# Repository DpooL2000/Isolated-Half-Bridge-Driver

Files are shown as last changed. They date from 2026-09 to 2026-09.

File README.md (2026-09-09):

# Isolated Half-Bridge Motor Driver

A robust, single half-bridge motor driver featuring galvanic PWM isolation and high-resolution bidirectional current sensing. Designed to safely interface a microcontroller with high-voltage motor rails while providing precise analog current feedback.



## Project Status
- **Hardware:** Complete (KiCad schematic and PCB layout finalized).
- **Firmware:** C++ driver code currently in development.

## Key Hardware Specifications
* **Gate Driver:** IR2101 with bootstrap topology (1N5819 diode / 1uF cap).
* **Power Stage:** 2x IRFZ44N N-Channel MOSFETs with 1000uF bulk smoothing.
* **Galvanic Isolation:** 2x 6N137 high-speed optocouplers protecting the logic side.
* **Current Sensing:** AD8418 bidirectional amplifier across an R002 milliohm shunt, heavily filtered (10Ω/10nF/1nF).
* **Reference Voltage:** Buffered 1.65V rail generated via MCP6002 for center-biased bidirectional sensing.

## Interface & Pinout

### Logic Side (Low Voltage)
* **PWM_H / PWM_L:** 2-Channel high-speed logic inputs (isolated via 6N137).
* **I_SENSE_OUT:** Amplified analog voltage representing motor current (centered at 1.65V).
* **VCC_LOGIC:** Input for the onboard LDO stepping down to power the opto-secondaries and IR2101.
* **GND:** Logic ground.

### Power Side (High Voltage)
* **MOTOR_V+:** Main high-voltage power rail.
* **MOTOR_OUT:** Half-bridge switching output to the motor.
* **GND_PWR:** Power ground (isolated from logic ground).

## Repository Structure
* `/Hardware` - KiCad project files (`.kicad_pro`, `.kicad_sch`, `.kicad_pcb`).
* `/Docs` - PDF schematics, board renders, and full CSV Bill of Materials.
* `/Firmware` - Placeholder for the upcoming C++ hardware abstraction and control classes. 

## Usage Notes
The design utilizes a bootstrap capacitor (C3) for the high-side MOSFET. The low-side MOSFET must be periodically pulsed on to recharge the bootstrap capacitor; do not attempt 100% duty cycle on the high side.

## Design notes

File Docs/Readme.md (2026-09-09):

# Subcircuit Documentation

## 1. Optocoupler Isolation Stage
This section safely isolates the low-voltage control logic from the high-voltage motor drive circuitry, preventing transient spikes from damaging the microcontroller.



* The circuit utilizes two 6N137 high-speed optocouplers (U11 and U4) to provide galvanic isolation for the incoming PWM signals.
* Control signals enter through a 2-pin screw terminal (J3) and pass through 330Ω current-limiting resistors (R1, R2) to drive the internal LEDs of the optocouplers.
* The secondary side of the optocouplers is powered by a 5V rail, decoupled by 0.1uF capacitors (C14, C13).
* The open-drain outputs are pulled up to the 3.3V logic rail via 1kΩ resistors (R3, R4), resulting in the isolated `CH` and `CNH` control signals.

## 2. Power Supply & Voltage Reference
This stage regulates the main battery voltage into clean logic levels and generates a stable center-bias voltage for bidirectional current sensing.



* The main battery voltage (`+BATT`) from screw terminal J1 is stepped down to 5V by an AMS1117-5.0 linear regulator (U6).
* A second regulator, an AMS1117-3.3 (U5), steps the voltage down further to provide a 3.3V rail for logic-level pull-ups and amplifier supply.
* Standard 10uF and 0.1uF capacitors are utilized on the regulator inputs and outputs for stability and transient suppression.
* A precise 1.65V reference voltage is generated using a 50% voltage divider consisting of two 10kΩ resistors (R5, R6) connected across the 3.3V rail. 
* This divider is buffered by an LMH6611 operational amplifier (U2) configured as a unity-gain follower, providing a low-impedance 1.65V source.

## 3. Half-Bridge & Bootstrap Driver
This high-power switching stage translates the isolated logic signals into the high current required to drive the motor.



* An IR2101 high/low-side driver IC (U8) manages the switching of two IRFZ44N N-channel power MOSFETs (Q1, Q2) configured in a half-bridge topology.
* Because an N-channel MOSFET on the high side requires a gate voltage higher than the main battery rail (`+BATT`), a bootstrap circuit is implemented using a 1N5819 Schottky diode (D3) and a 1uF capacitor (C3).
* The isolated control signals `CH` and `CNH` are pulled up to 5V via 1kΩ resistors (R8, R7) before feeding into the driver IC.
* The driver outputs connect to the MOSFET gates through 22Ω resistors (R13, R14) to dampen ringing and limit peak switching current.
* A 1000uF bulk electrolytic capacitor (C10) sits across the high-voltage rail and ground to smooth out heavy current demands from the motor.

## 4. Current Sensing & Analog Filtering
This circuit measures the physical output current of the half-bridge and translates it into a clean, center-biased analog voltage.



* Motor current flows through an R002 (2mΩ) inline shunt resistor (R19), creating a small voltage drop proportional to the current.
* An AD8418 high-resolution current sense amplifier (U1) measures this differential voltage.
* To reject high-frequency switching noise, the inputs to the amplifier are heavily filtered using 10Ω resistors (R25, R26), a 10nF differential capacitor (C19), and 1nF common-mode capacitors (C27, C26).
* The amplifier's reference pins (REF1 and REF2) are tied to the buffered 1.65V rail. This center-biases the output, allowing the microcontroller to read both forward and reverse motor currents.
* The final analog output passes through an RC low-pass filter (330Ω R9 and 100nF C11) before exiting via the `current analog reading` connector (J4).

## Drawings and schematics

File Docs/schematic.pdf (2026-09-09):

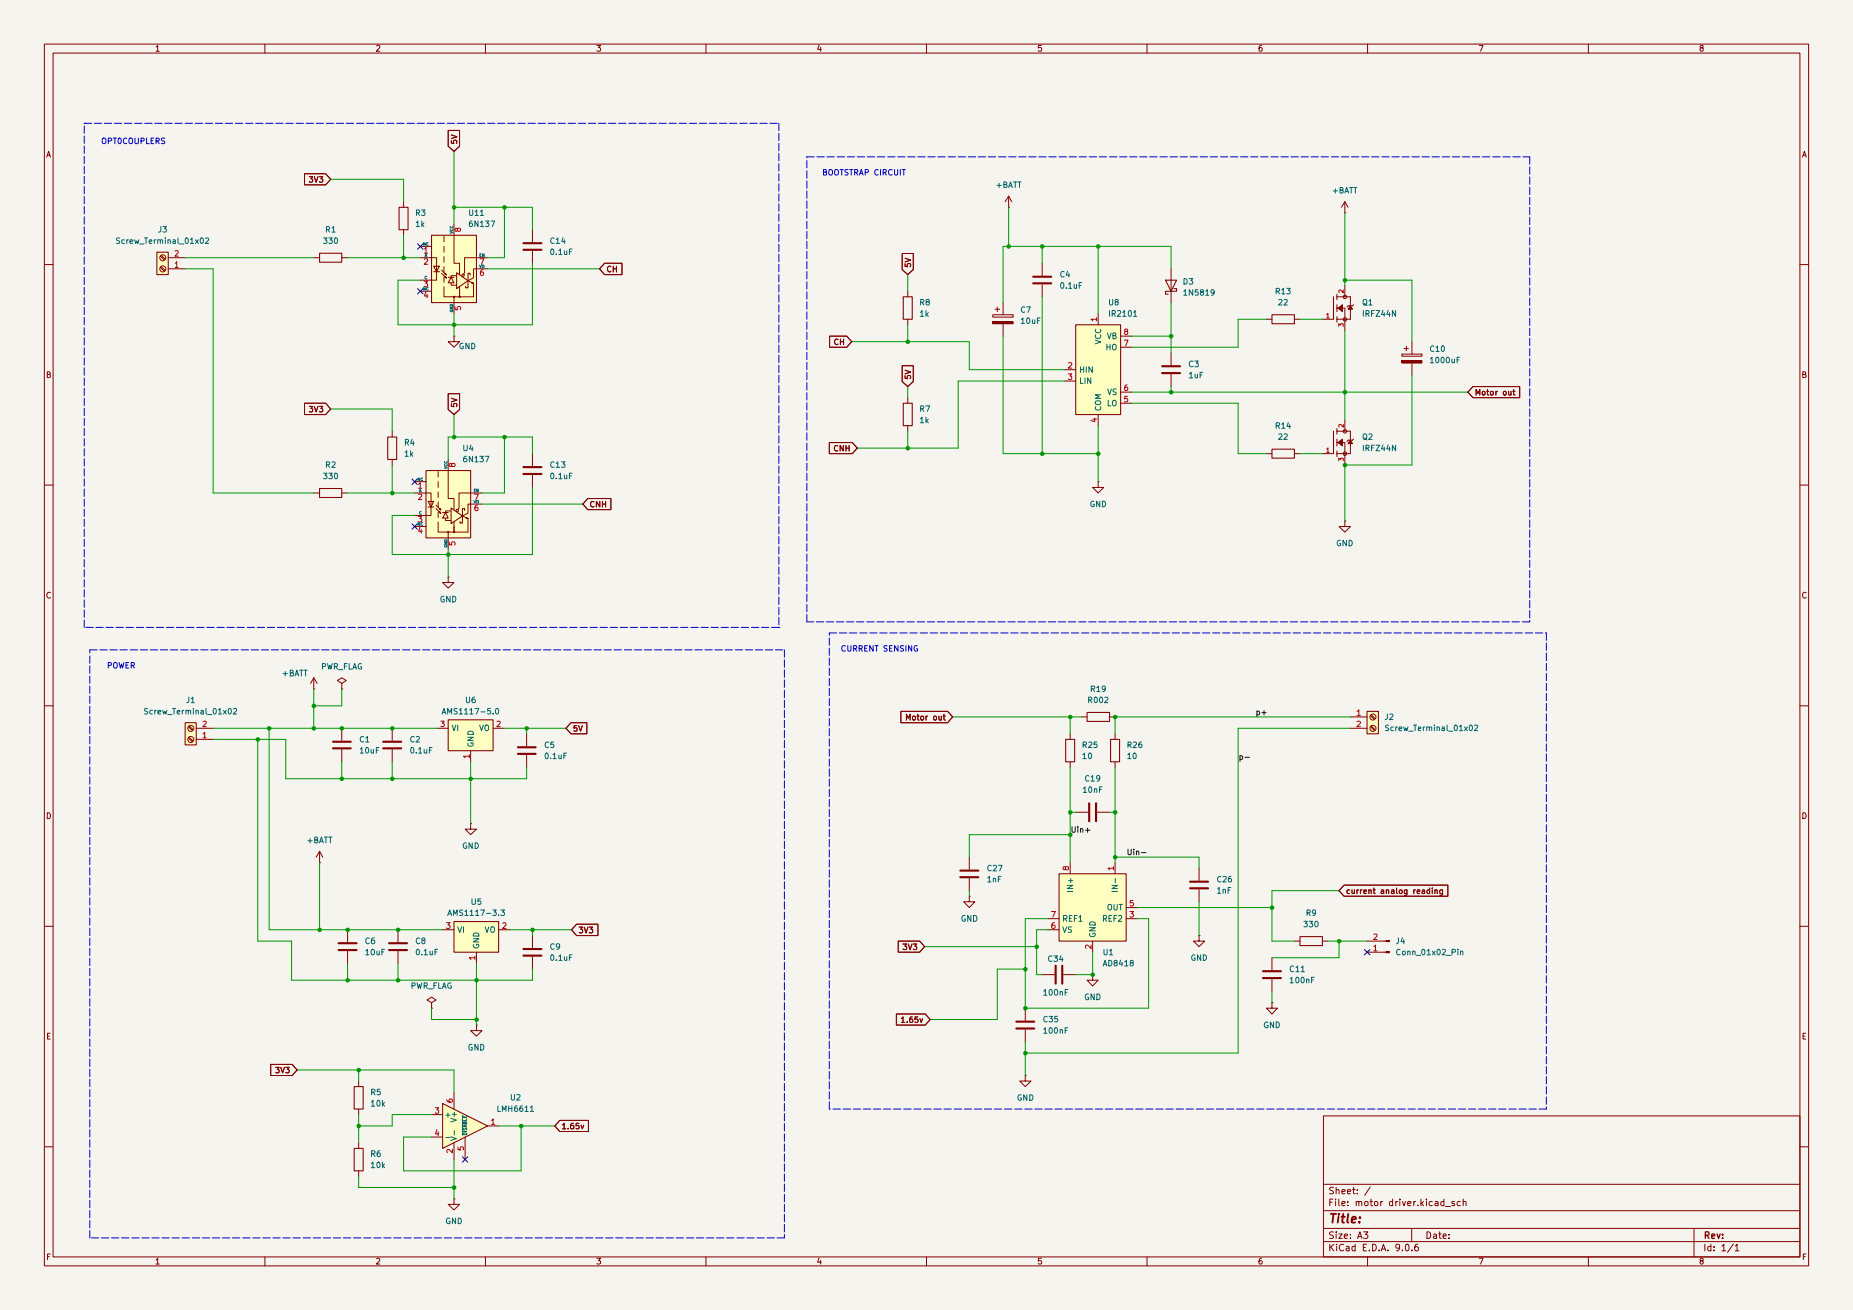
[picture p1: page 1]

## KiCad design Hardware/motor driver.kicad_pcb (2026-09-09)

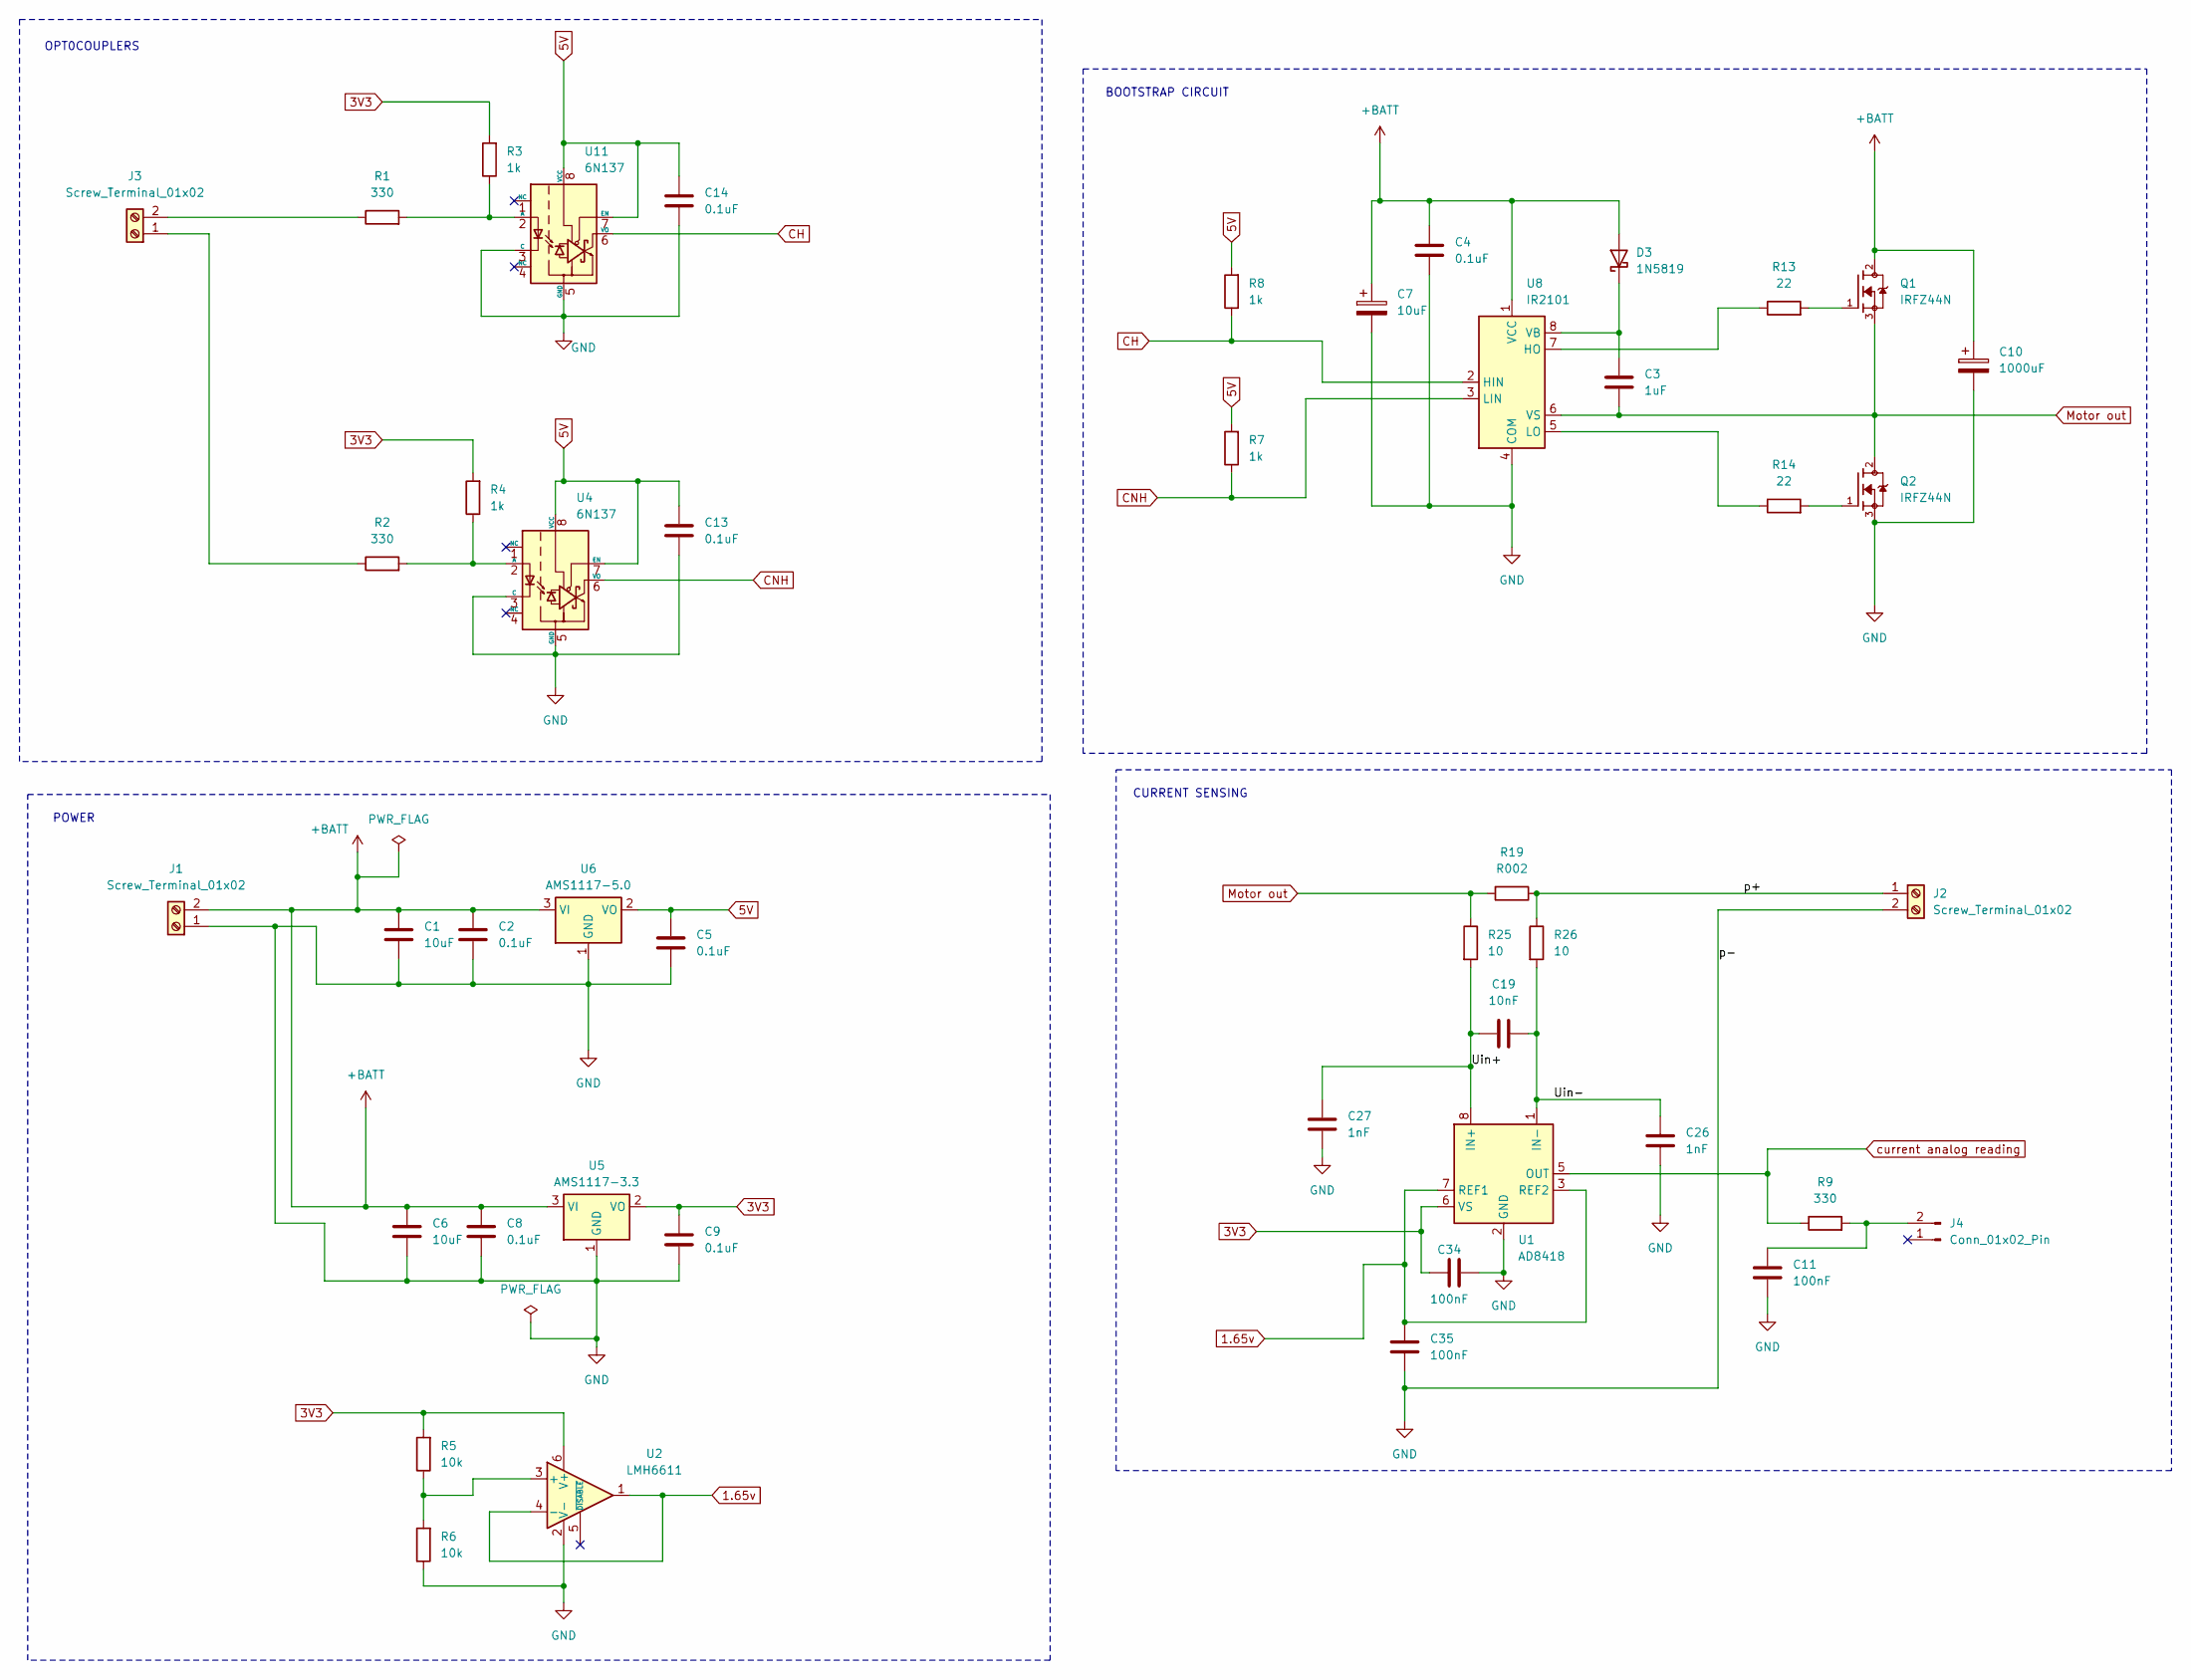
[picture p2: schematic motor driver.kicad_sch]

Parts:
C1, C6: 10uF; C_Disc_D3.0mm_W2.0mm_P2.50mm
C2, C4, C5, C8, C9, C13, C14: 0.1uF; C_Disc_D3.0mm_W2.0mm_P2.50mm
C3: 1uF; C_Disc_D3.0mm_W2.0mm_P2.50mm
C7: 10uF; C_Radial_D5.0mm_H5.0mm_P2.00mm
C10: 1000uF; CP_Radial_D10.0mm_P5.00mm
C11, C34, C35: 100nF; C_Disc_D3.0mm_W2.0mm_P2.50mm
C19: 10nF; C_Disc_D3.0mm_W2.0mm_P2.50mm
C26, C27: 1nF; C_Disc_D3.0mm_W2.0mm_P2.50mm
D3: 1N5819; D_DO-41_SOD81_P2.54mm_Vertical_AnodeUp
J1, J2: Screw_Terminal_01x02; TerminalBlock_MaiXu_MX126-5.0-02P_1x02_P5.00mm
J3: Screw_Terminal_01x02; TerminalBlock_Xinya_XY308-2.54-2P_1x02_P2.54mm_Horizontal
J4: Conn_01x02_Pin; PinHeader_1x02_P2.54mm_Vertical
Q1, Q2: IRFZ44N; TO-220-3_Vertical; PARTREV 09/21/10
R1, R2, R9: 330; R_Axial_DIN0204_L3.6mm_D1.6mm_P1.90mm_Vertical
R3, R4, R7, R8: 1k; R_Axial_DIN0204_L3.6mm_D1.6mm_P1.90mm_Vertical
R5, R6: 10k; R_Axial_DIN0204_L3.6mm_D1.6mm_P1.90mm_Vertical
R13, R14: 22; R_Axial_DIN0204_L3.6mm_D1.6mm_P1.90mm_Vertical
R19: R002; R_4020_10251Metric
R25, R26: 10; R_Axial_DIN0204_L3.6mm_D1.6mm_P1.90mm_Vertical
U1: AD8418; SOIC-8_3.9x4.9mm_P1.27mm
U2: LMH6611; TSOT-23-6
U4, U11: 6N137; DIP-8_W7.62mm
U5: AMS1117-3.3; SOT-223-3_TabPin2
U6: AMS1117-5.0; SOT-223-3_TabPin2
U8: IR2101; DIP-8_W7.62mm_LongPads

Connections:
1.65v: C35.1, U1.3 (REF2), U1.7 (REF1), U2.1, U2.4 (-)
3V3: C9.1, C34.2, R3.2, R4.2, R5.2, U1.6 (VS), U2.6 (V+), U5.2 (VO)
5V: C5.1, C13.1, C14.1, R7.2, R8.2, U4.7 (EN), U4.8 (VCC), U6.2 (VO), U11.7 (EN), U11.8 (VCC)
+BATT: C1.1, C2.1, C4.1, C6.1, C7.1, C8.1, C10.1, D3.2 (A), J1.2, Q1.2, U5.3 (VI), U6.3 (VI), U8.1 (VCC)
/Uin+: C19.2, C27.1, R25.2, U1.8 (IN+)
/Uin-: C19.1, C26.1, R26.2, U1.1 (IN-)
/p+: J2.1, R19.1, R26.1
CH: R8.1, U8.2 (HIN), U11.6 (VO)
CNH: R7.1, U4.6 (VO), U8.3 (LIN)
GND: C1.2, C2.2, C4.2, C5.2, C6.2, C7.2, C8.2, C9.2, C10.2, C11.1, C13.2, C14.2, C26.2, C27.2, C34.1, C35.2, J1.1, J2.2, Q2.3, R6.1, U1.2 (GND), U2.2 (V-), U4.3 (C), U4.5 (GND), U5.1 (GND), U6.1 (GND), U8.4 (COM), U11.3 (C), U11.5 (GND)
Motor out: C3.2, Q1.3, Q2.2, R19.2, R25.1, U8.6 (VS)
unnamed: C3.1, D3.1 (K), U8.8 (VB)
unnamed: J3.1, R2.1
unnamed: J3.2, R1.1
unnamed: C11.2, J4.2, R9.2
unnamed: Q1.1, R13.2
unnamed: Q2.1, R14.2
unnamed: R5.1, R6.2, U2.3 (+)
unnamed: R2.2, R4.1, U4.2 (A)
unnamed: R13.1, U8.7 (HO)
unnamed: R14.1, U8.5 (LO)
unnamed: R1.2, R3.1, U11.2 (A)
current analog reading: R9.1, U1.5 (OUT)

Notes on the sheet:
OPT0COUPLERS
CURRENT SENSING
POWER
BOOTSTRAP CIRCUIT

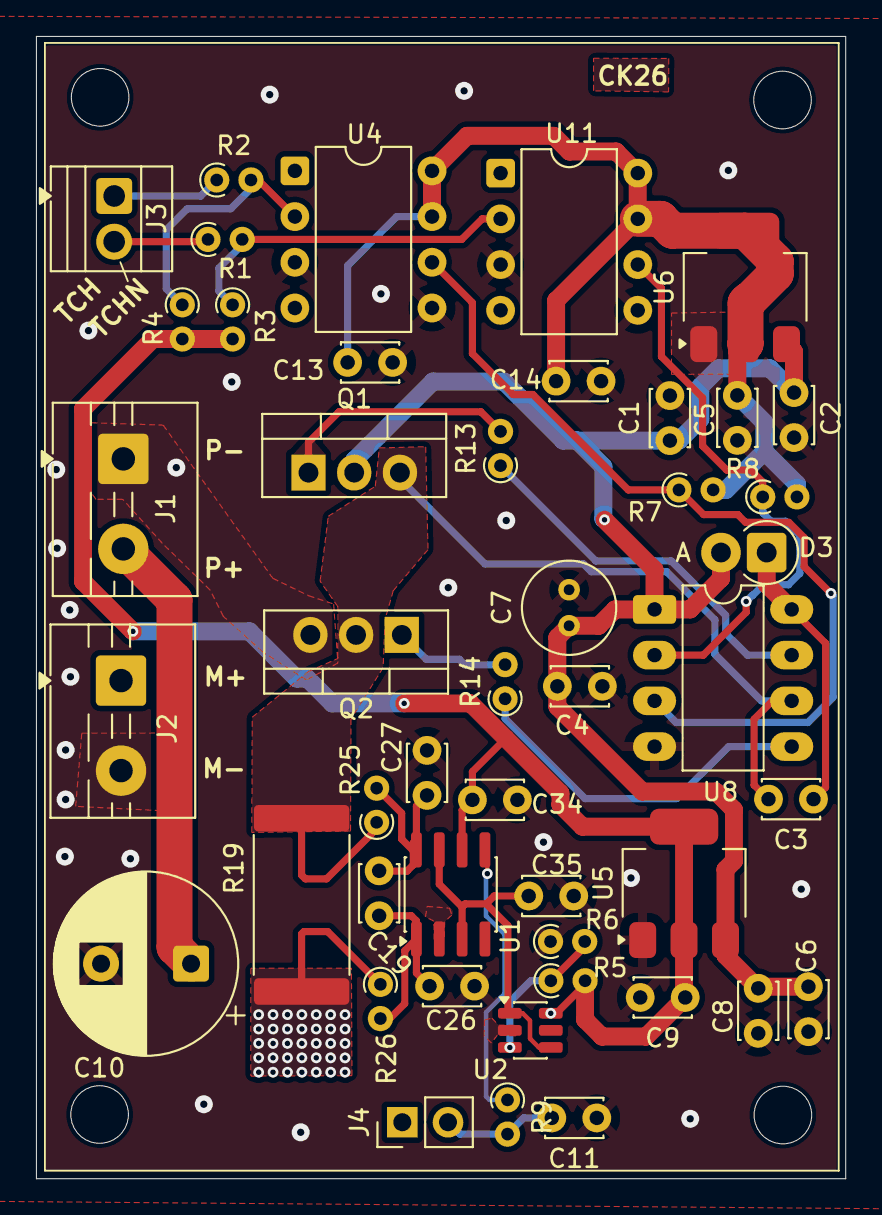
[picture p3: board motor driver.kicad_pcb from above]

Board: 2 copper layers, 45.0 x 63.5 mm, 46 parts (0 on the bottom side), 23 nets.

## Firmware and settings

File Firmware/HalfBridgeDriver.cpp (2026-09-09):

#include "HalfBridgeDriver.h"
#include "hw_timers.h"

HalfBridgeDriver::HalfBridgeDriver(uint8_t currentSensePin) {
    _sensePin = currentSensePin;
}

void HalfBridgeDriver::begin() {
    // 1. Fail-safe: Force outputs LOW before timer takes over
    pinMode(SAFE_PWM_H, OUTPUT);
    pinMode(SAFE_PWM_L, OUTPUT);
    digitalWrite(SAFE_PWM_H, LOW);
    digitalWrite(SAFE_PWM_L, LOW);

    // 2. Attach the hardware timer
    hw_timer_init();
}

void HalfBridgeDriver::setDutyCycle(float percent) {
    if (percent < 0.0) percent = 0.0;
    
    // Clamp to 95% max duty cycle to allow the bootstrap capacitor to recharge
    if (percent > 95.0) percent = 95.0; 
    
    hw_pwm_update(percent);
}

void HalfBridgeDriver::emergencyStop() {
    hw_force_low();
}

float HalfBridgeDriver::readCurrentAmps() {
    int raw = analogRead(_sensePin);
    
    // Convert 10-bit ADC raw value to voltage (Assuming 3.3V reference)
    float voltage = (raw / 1023.0) * 3.3; 
    
    // Calculate actual current: I = (Vout - Vref) / (Gain * Rshunt)
    float current = (voltage - _vRef) / (_ampGain * _shuntResistor);
    
    return current;
}

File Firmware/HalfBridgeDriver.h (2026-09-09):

#ifndef HALF_BRIDGE_DRIVER_H
#define HALF_BRIDGE_DRIVER_H

#include <Arduino.h>

// Architecture Guards
#if defined(__AVR_ATmega328P__) || defined(__AVR_ATmega168__)
    #define SAFE_PWM_H 9
    #define SAFE_PWM_L 10
#elif defined(ARDUINO_ARCH_STM32)
    // STM32 target pins depend on the specific series (e.g., F1 vs G4)
    #define SAFE_PWM_H PA8 // TIM1_CH1
    #define SAFE_PWM_L PA7 // TIM1_CH1N
#else
    #error "DANGER: Architecture not supported! Complementary PWM with deadtime is not implemented for this board."
#endif

class HalfBridgeDriver {
public:
    HalfBridgeDriver(uint8_t currentSensePin);
    
    void begin();
    void setDutyCycle(float percent);
    void emergencyStop();
    float readCurrentAmps();

private:
    uint8_t _sensePin;
    const float _vRef = 1.65;
    const float _shuntResistor = 0.002;
    const float _ampGain = 20.0;
};

#endif
